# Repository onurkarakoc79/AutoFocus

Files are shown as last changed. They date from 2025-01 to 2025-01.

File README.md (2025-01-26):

## Automatic Camera Focusing System
# Overview
This project involves the development of an automatic camera focusing system utilizing a combination of Raspberry Pi, OpenCV, Python, and a servo motor. The system automates the traditionally manual process of focus adjustment, providing real-time feedback and enabling precise focus for photography, surveillance, and computer vision applications.

# Objectives
1. Automated Focus Adjustment: Control the camera lens with a servo motor for precise, remote adjustments.
2. Image Processing with OpenCV: Use a delentropy-based algorithm to assess the clarity of images.
3. Real-Time Feedback: Provide immediate focus status and save images once focused.
4. Integration: Seamlessly combine components like Raspberry Pi, servo motor, and camera module.
5. Optimization: Evaluate and refine the system for improved accuracy and efficiency.
# Features
* Focus adjustment through a servo-controlled camera lens.
* Image sharpness analysis using delentropy metrics.
* Efficient and reliable operation in varying light conditions.
* Compact design with 3D-printed custom parts.
## Components
# Hardware
* Raspberry Pi v2: Central processing unit for system integration.
* MG995 Servo Motor: Adjusts the lens focus ring.
* Raspberry Pi HQ Camera Module: Captures high-resolution images.
* LM2596 Voltage Regulator: Provides stable power supply.
* Additional components: LED lamp, 12V power supply, trapezoidal lead screw, and 3D-printed mechanical parts.
# Software
* Raspbian OS: Operating system for Raspberry Pi.
* OpenCV Library: Image processing and analysis.
* PiGPIO Library: Optimized PWM signal generator for servo motor control.
# Installation and Setup
1. Install Raspbian OS on Raspberry Pi.
2. Install the OpenCV library:

```bash
   sudo apt-get install python3-opencv
```
3. Install the PiGPIO library like described in the website:
<pre> https://abyz.me.uk/rpi/pigpio/download.html </pre>

4. Connect hardware components as per the circuit schematic.

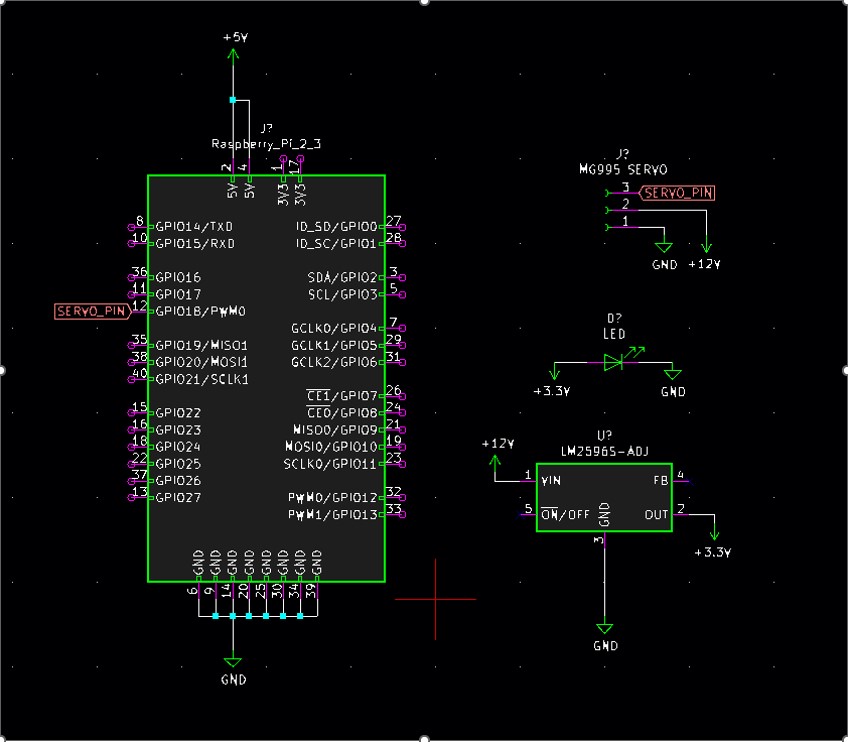
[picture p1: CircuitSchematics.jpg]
Focus Adjustment Schematic


5. Run the focus adjustment script:

```bash
   git clone https://github.com/onurkarakoc79/AutoFocus
```

# Usage
1. Power on the Raspberry Pi and connected components.
2. Adjust focus by pointing the camera at the target object.
3. Run the following script
   ```bash
    python3 AutoFocus.py
   ```
4. The system will analyze the image's clarity and automatically adjust the focus.
# Applications
* Photography: Enhanced focus precision for capturing sharp images.
* Surveillance: Continuous focus adjustments for monitoring.
* Microscopy: Precise focus on specimens for detailed analysis.
* Robotics: Improved navigation through real-time focus adjustments.
# Challenges and Solutions
* Low processing power: Optimized algorithms to focus on specific image regions.
* Servo jitter: Resolved by switching to the PiGPIO library.
* Lighting issues: Incorporated LED lamp for better illumination.
# Future Improvements
* Enhancing focus adjustment speed.
* Reducing system size for compact applications.
* Extending use cases to include robotics and industrial automation.

## Contact

If you have any questions, feedback, or inquiries related to the project, feel free to reach out to me:

My personal mail: onurkarakoc79@gmail.com

I appreciate your interest in my projects and look forward to collaborating with you in the fascinating field of scientific exploration and discovery.

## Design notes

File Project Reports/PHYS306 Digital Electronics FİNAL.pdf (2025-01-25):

## PHYS306 Digital Electronics

## Final Project: Automatic focusing of a camera on an

object.

Objectives:

The primary objective of this project is to develop an advanced automatic focus system using OpenCV, Python, a Raspberry Pi, and a servo motor. The system aims to revolutionize the traditional manual focus adjustment process by automating it through the integration of various technologies.

The first objective is to design a mechanism that enables automated focus adjustment. This will be accomplished by employing a servo motor to rotate the camera lens, allowing for precise and remote adjustments. The servo motor will be controlled through the Raspberry Pi, enabling convenient and accurate focus changes without the need for manual intervention.

The second objective involves implementing an image processing algorithm using OpenCV and Python. This algorithm will be responsible for analyzing the sharpness and clarity of captured images to determine their focus status. The delentropy metric, which measures the image's entropy and provides a measure of its clarity, will be utilized for this purpose. By calculating the delentropy of each image, the algorithm will classify them as either focused or unfocused.

Real-time focus feedback constitutes the third objective. The system will provide immediate feedback on the focus status of the camera and save the image to raspberry pi when camera on the focus status.

The fourth objective is to seamlessly integrate the various components of the system using a Raspberry Pi. Acting as the central control unit, the Raspberry Pi will facilitate
communication between the servo motor, the camera module, and the image processing algorithm. This integration will enable smooth coordination among these components, ensuring efficient and accurate automatic focus adjustments.

Lastly, the project aims to evaluate and optimize the system's performance. Through comprehensive evaluations and comparisons, the effectiveness and accuracy of the automatic focus system will be assessed. Potential optimizations will be explored to enhance the speed and precision of the focus adjustment mechanism and image processing algorithm. By continually refining and improving the system, it can offer a reliable and user-friendly solution for automatic focus adjustment in a wide range of applications, including photography, surveillance systems, and computer vision projects.

INTRODUCTION:

In the field of photography, achieving accurate focus is essential to capture sharp and clear images. Manual focus adjustments can be time-consuming and often require constant monitoring. To address this challenge, we present a project aimed at developing an automatic focus system using OpenCV, Python, a Raspberry Pi, and a servo motor. This system leverages the power of image processing algorithms and automation to achieve precise focus settings in real-time.

The primary objective of this project is to design and implement a reliable and user-friendly automatic focus mechanism that eliminates the need for manual intervention. By integrating OpenCV, a popular computer vision library, with a Raspberry Pi microcontroller and a servo motor, we aim to create a system that can dynamically adjust the camera focus based on image analysis.

The project employs the delentropy metric, a measure of image entropy, as the foundation for the image processing algorithm. By continuously analyzing the sharpness and clarity of captured images using delentropy, the algorithm determines the focus status. Once optimal focus is achieved, the system automatically captures a photo as immediate feedback.

The automatic focus system offers several advantages over traditional manual methods. Firstly, the system's ability to analyze and assess focus quality in real-time eliminates the need for constant manual monitoring, allowing users to focus on capturing the perfect shot.Additionally, the automatic focus system enhances the consistency and reliability of focus settings. By utilizing an automated mechanism driven by a servo motor, the system can achieve precise and repeatable focus adjustments, reducing the likelihood of human error or inconsistencies between shots.

The applications of this project extend beyond photography. For example, in surveillance systems, the automatic focus system can continuously monitor and adjust the focus of cameras, ensuring clear and sharp imagery of critical areas. In microscopy, the system can be utilized to maintain precise focus on specimens, aiding researchers in capturing detailed images for analysis.

Furthermore, in robotics and autonomous systems, the automatic focus system can be integrated into vision-based navigation algorithms. By adjusting the focus of cameras in real-time, robots can perceive their surroundings more accurately, leading to improved object recognition, obstacle detection, and path planning.

In conclusion, this project aims to create an automatic focus system that revolutionizes the traditional manual focus adjustment process. By combining OpenCV, Python, a Raspberry Pi, and a servo motor, we strive to provide photographers and other professionals with an efficient, reliable, and user-friendly solution for achieving precise focus settings. The subsequent sections of this report will delve into the details of the system's design, equipment used, procedures employed, calculations performed, and the results obtained, followed by discussions and comments on the system's performance and potential areas of improvement.

Equipment:

- Raspberry Pi v2: A version 2 of the Raspberry Pi, a small single-board computer.
- LM2596 Voltage Regulator
- 3.3V LED: An LED (Light-Emitting Diode) that operates on a voltage of 3.3V.
- MG995 Servo Motor:
- 12V:10A Power supply
- 3D Printed custom parts: Custom-designed parts that are manufactured using a 3D printing process, allowing for unique shapes and specifications.
- Couplings
- Trapezoidal lead screw
- 8mm Chrome-plated rod
- 5V:1.5A power supply
- 8mm roller
- 8mm gt2 pulley
- 8mm linear rollers

PROCEDURE:

SOFTWARE:

1. The Raspbian operating system will be installed on the raspberry pi card in the software part.
a. Raspbian is a specialized operating system built specifically for the Raspberry Pi. It is based on the Linux Debian distribution and provides a lightweight and user-friendly environment for running applications on the Raspberry Pi hardware. Raspbian comes with pre-installed software packages and tools, making it a popular choice for various projects and applications.
2. OpenCV library will be downloaded to raspberry pi.
a. OpenCV, or Open-Source Computer Vision Library, is a popular open-source software library used for computer vision and image processing tasks. It provides a wide range of functions and algorithms to analyze and manipulate images and videos. OpenCV is widely used in various fields, such as robotics, surveillance, augmented reality, and medical imaging. Its versatility and extensive documentation make it a valuable tool for developers working with computer vision applications.
3. Functions that can detect whether the captured image is clear or not will be investigated.
a. The cv2.Laplacian function in OpenCV is used for performing the Laplacian edge detection on an image. It calculates the Laplacian gradient of the image, which highlights regions of rapid intensity changes or edges. The Laplacian operator is a second-order derivative operator that measures the rate of change of the image intensity. It is commonly used for edge detection because it responds strongly to areas of rapid intensity variation. The cv2.Laplacian function applies the Laplacian operator to each pixel in the image and computes the Laplacian gradient. The function takes the input image as its parameter and returns the output image, which represents the edges or areas of rapid intensity changes. The resulting image is typically in grayscale, where brighter pixels indicate stronger edges. The cv2.Laplacian function uses a 3x3 kernel by default, but you can specify a different kernel size if needed. The kernel determines the neighborhood around each pixel that is used for calculating the Laplacian gradient. Overall, the cv2.Laplacian function is a powerful tool for detecting edges and areas of rapid intensity changes in an image, providing valuable information for various computer vision tasks such as object recognition, image segmentation, and feature extraction.
b. The cv2.GaussianBlur function in OpenCV is used for applying a Gaussian blur or smoothing effect to an image. Gaussian blur is a widely used image filtering technique that helps reduce noise and details in an image while preserving its overall structure. The function takes the input image and two additional parameters as input: the kernel size and the standard deviation of the Gaussian distribution. The kernel size determines the size of the filter window, which defines the neighborhood of pixels used for the blurring operation. The standard deviation controls the spread of the Gaussian distribution and influences the amount of blurring applied. When the cv2.GaussianBlur function is called, it convolves each pixel in the image with a Gaussian kernel. The convolution process involves calculating the weighted average of the pixel values within the kernel window. The weights are determined by the Gaussian distribution, with the highest weight assigned to the central pixel and decreasing weights assigned to the surrounding pixels. By convolving the image with the Gaussian kernel, the function effectively replaces each pixel value with the weighted average of its neighborhood, resulting in a smoothed and blurred version of the original image. The amount of blurring depends on the kernel size and standard deviation parameters. Larger kernel sizes and higher standard deviations result in stronger blurring effects. The cv2.GaussianBlur function is commonly used as a preprocessing step in various computer vision tasks. It helps reduce noise, remove high-frequency details, and create smoother images that are more suitable for subsequent operations such as edge detection, feature extraction, or image recognition.
c. The detect_focus_delentropy function aims to assess the focus measure of a grayscale image using the delentropy method. This method focuses on analyzing the distribution of gradients, which are changes in pixel intensities across neighboring regions. To calculate the focus measure, the function first computes the horizontal and vertical gradients of the image. This is done by subtracting the pixel values of adjacent columns and rows, respectively. By combining these gradients, an overall gradient image is obtained, representing the magnitude and direction of changes in pixel intensities. Next, the function constructs a 2D histogram based on the gradient values, which captures the distribution of these values across the image. The histogram is normalized to ensure that each bin represents a proportional frequency of gradient occurrences. The histogram is then processed by applying the logarithm (base
2) to each bin value, resulting in delentropy values. These delentropy values represent the information content or complexity associated with different gradient magnitudes. By summing up these delentropy values, an overall measure of the image's entropy is obtained. Dividing the computed entropy by 2, following the Papoulis generalized sampling method, yields the final focus measure. This measure serves as a quantitative indicator of the image's sharpness and clarity, allowing for the determination of the optimal focus setting for capturing high-quality images. In summary, the detect_focus_delentropy function utilizes the delentropy method to evaluate the focus quality of a grayscale image by analyzing the distribution of gradients. This approach provides valuable insights into the image's level of detail and sharpness, facilitating the identification of the ideal focus point for image capture.

ELECTRONICS:

1. The raspberry pi v2 will be powered and operated.
a. The Raspberry Pi 2 is a small, affordable, and versatile single-board computer. It offers improved specifications and features compared to previous models. With its compact size and GPIO pins for connecting external components, it is widely used for educational, DIY, and IoT projects. It runs various operating systems and provides a platform for learning and innovation.
2. MG995 servo motor will be driven with the help of raspberry pi and the angle variable will enable the motor to go to the desired point.
a. The MG995 servo motor is a popular type of analog servo motor commonly used in robotics and automation projects. This servo motor is known for its high torque output and accuracy. It operates based on the principle of pulse width modulation (PWM). The motor consists of a DC motor, a control circuit, and a feedback potentiometer. When a PWM signal is applied to the servo motor, it interprets the signal's pulse width to determine the desired position. The PWM signal typically has a frequency of 50 Hz, with a pulse width ranging from 1 ms to 2 ms. The motor's control circuit uses this pulse width information to drive the DC motor to the corresponding position. The control circuit inside the servo motor compares the received pulse width with the current position feedback from the potentiometer. If the two values differ, the control circuit adjusts the motor's speed and direction to move towards the desired position. Once the position matches the input signal, the control circuit stops the motor, maintaining the position until a new signal is received.
3. The Raspberry Pi HQ Camera Module camera will be connected to Raspberry Pi and image will be taken.
a. The Raspberry Pi HQ Camera Module is an official camera accessory designed specifically for the Raspberry Pi single-board computer. It is a high-quality camera module that offers advanced imaging capabilities for various applications. The HQ Camera Module features a 12.3-megapixel Sony
IMX477 image sensor, which provides excellent image quality and low-light performance. It supports interchangeable lenses, allowing users to choose different focal lengths and lens types based on their specific needs. This flexibility enables a wide range of photography and video recording possibilities. The camera module connects directly to the Raspberry Pi board via a dedicated CSI (Camera Serial Interface) port, ensuring a seamless integration and easy setup. It is supported by the official Raspberry Pi camera software, which provides a user-friendly interface and a range of features for capturing and processing images. With the Raspberry Pi HQ Camera Module, users can capture high-resolution still images, record videos in various formats, and apply image processing techniques using the Raspberry Pi's computing power. It is suitable for applications such as surveillance systems, home automation, robotics, scientific imaging, and more.
4. With the LM2596, the output of the 12V power supply will be reduced to 3.3V and the LED will be operated.
a. The LM2596 voltage regulator is a versatile integrated circuit (IC) commonly used for voltage regulation. It efficiently converts higher input voltages to lower output voltages, providing stable power for electronic devices. Its adjustable output voltage and built-in protection features make it a popular choice for various applications.

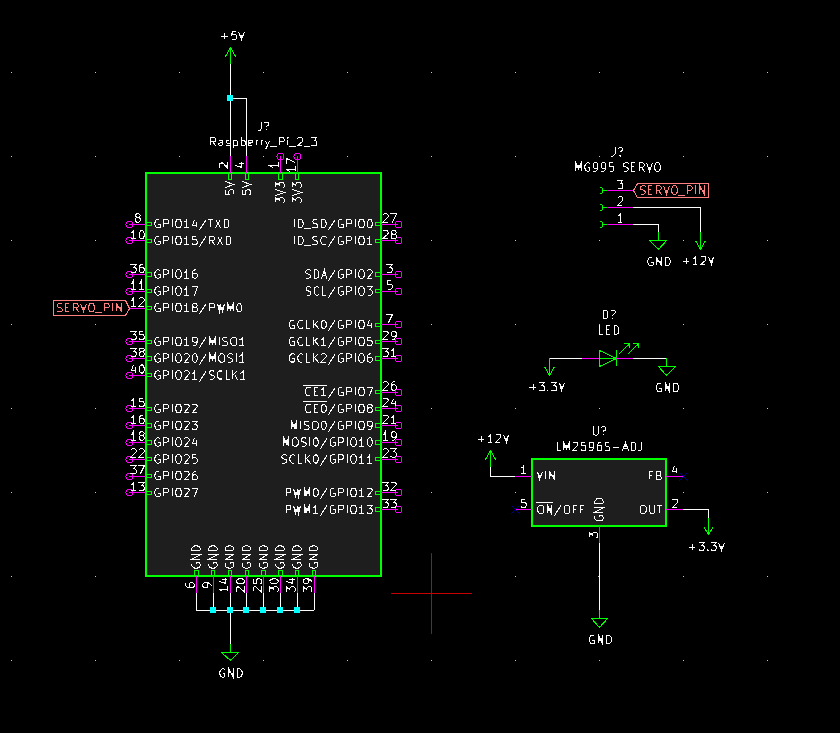
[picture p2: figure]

MECHANICHS:

1. Spur gears will be designed to control the focus ring of the lens by servo motor.
a. An adjustable focus lens with a ring refers to a type of lens that allows the user to manually adjust the focus by rotating a ring on the lens barrel. This ring controls the position of lens elements, changing the distance between them and adjusting the focal length of the lens. By rotating the ring, the user can achieve a sharp focus at different distances, allowing for versatile focusing capabilities in photography or other optical applications. This feature provides greater control and flexibility in capturing clear and detailed images or videos.
b. Module 2 spur gears refer to a type of gear mechanism that uses cylindrical gears with a standardized module of 2. The module represents the size and spacing of the

Figure 1: The circuit schematic of project gear teeth and determines their compatibility with other gears. Spur gears have straight teeth that run parallel to the gear axis and mesh together to transfer rotational motion between two parallel shafts. The module 2 designation indicates the specific size and pitch of the gear teeth, allowing for precise gear meshing and smooth power transmission. Module 2 spur gears are commonly used in various mechanical systems, such as robotics, machinery, and automotive applications, where reliable and efficient torque transfer is required.
c. The utilization of gears with 27 and 26 teeth was employed as a preventive measure against gear wear. The module 2 spur gears with these specific tooth counts were chosen to ensure a smooth and efficient transmission of motion. By using gears with different tooth counts, the system can distribute the load and minimize wear on individual gear teeth. This design choice enhances the overall durability and longevity of the gear mechanism, contributing to the reliable functioning of the system.
2. The x and y axes will be fixed with the help of two chrome shafts and linear bearings and the z axis will be moved using the trapezoidal shaft.
a. Linear rollers are mechanical components used for smooth and precise linear motion. They consist of cylindrical rollers mounted in a housing, allowing objects or loads to move along a straight path with minimal friction. They find applications in conveyor systems, sliding doors, robotics, and CNC machines, providing reliable and efficient linear movement.
b. A trapezoidal lead screw, also known as a trapezoidal thread or trapezoidal mill, is a type of mechanical component used for converting rotary motion into linear motion or vice versa. It features a trapezoidal-shaped thread profile on the surface, which allows for efficient and precise movement along its length when coupled with a corresponding nut. Trapezoidal lead screws are commonly used in applications such as CNC machines, 3D printers, and industrial machinery, offering reliable and accurate linear positioning capabilities.
3. Fixing parts designed from CAD programs will be printed with the 3D printer from PLA material.
a. PLA (Polylactic Acid) is a commonly used thermoplastic material in 3D printing. It is derived from renewable resources such as corn starch or sugarcane, making it environmentally friendly. PLA is known for its ease of use, low toxicity, and biodegradability. It has become popular in 3D printing due to its good printability, dimensional accuracy, and relatively low melting temperature.
b. 3D printing, also known as additive manufacturing, is a process of creating three-dimensional objects by depositing successive layers of material. It involves the use of a 3D printer, which reads a digital 3D model file and builds the object layer by layer. The printer melts or softens the PLA filament and extrudes it through a nozzle to create the desired shape. As each layer is added and solidified, the object gradually takes form. 3D printing offers versatility, allowing the production of complex geometries, prototypes, customized products, and even functional parts for various industries.

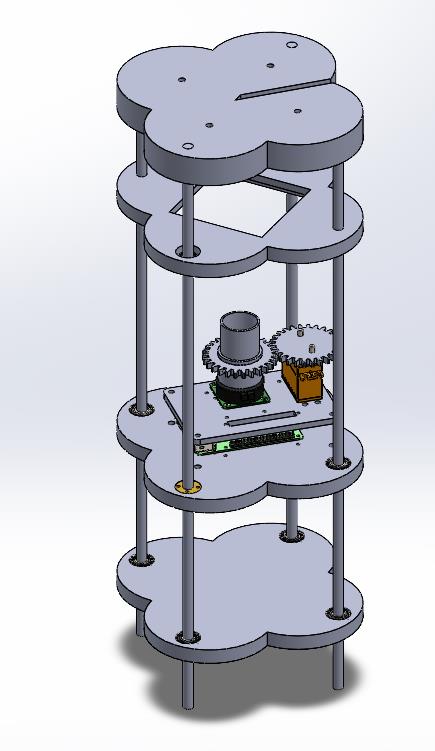
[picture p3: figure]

CALCULATİONS AND RESULTS:

SOFTWARE:

In the software development phase, the Raspberry Pi was initially set up with the Raspbian operating system, which serves as the foundation for running various applications. Subsequently, the OpenCV libraries were installed to leverage their extensive capabilities for image processing and analysis.

During the initial research phase, the Laplacian function, available in the OpenCV library, was explored as a potential method for assessing image clarity. The Laplacian function showed promising results in determining image sharpness. However, it became evident that relying solely on the Laplacian function was not sufficient, particularly in low-light conditions where its effectiveness diminished. To overcome this limitation, an adaptation of the Laplacian function using Gaussian blur was implemented. This modification aimed to improve performance in different lighting conditions.

However, the system's performance on the Raspberry Pi, which has relatively lower processing power compared to personal computers, proved to be insufficient. The computational demands of the modified Laplacian function pushed the Raspberry Pi to its limits, causing freezing and instability. As a result, alternative approaches were explored to accurately measure image sharpness.

Figure 2: The CAD drawing of mechanical parts of project

Through further investigation, the delentropy method was discovered as a viable alternative. The delentropy method proved to be reliable, particularly in low-light or high-light conditions. It was deemed more suitable for the project as it did not excessively strain the system. Consequently, the decision was made to adopt the delentropy method as the primary approach for assessing image sharpness.

To enhance program efficiency, a refinement was made by calculating the entropy of the specific point where focus was desired, rather than calculating the entropy of each pixel in the entire image. This optimization not only improved the program's efficiency but also provided users with the flexibility to focus on their desired point of interest. To facilitate point selection, the OpenCV function "setmousecallback" was utilized, enabling users to choose the desired focus point using a mouse input.

This iterative process of exploring different methods, adapting algorithms to varying lighting conditions, and ultimately adopting the delentropy method with optimized focus point selection has yielded a more robust and efficient automatic focus system. The subsequent sections of this report will delve into the specific procedures, calculations, and results obtained, followed by discussions on the system's performance and potential avenues for improvement.

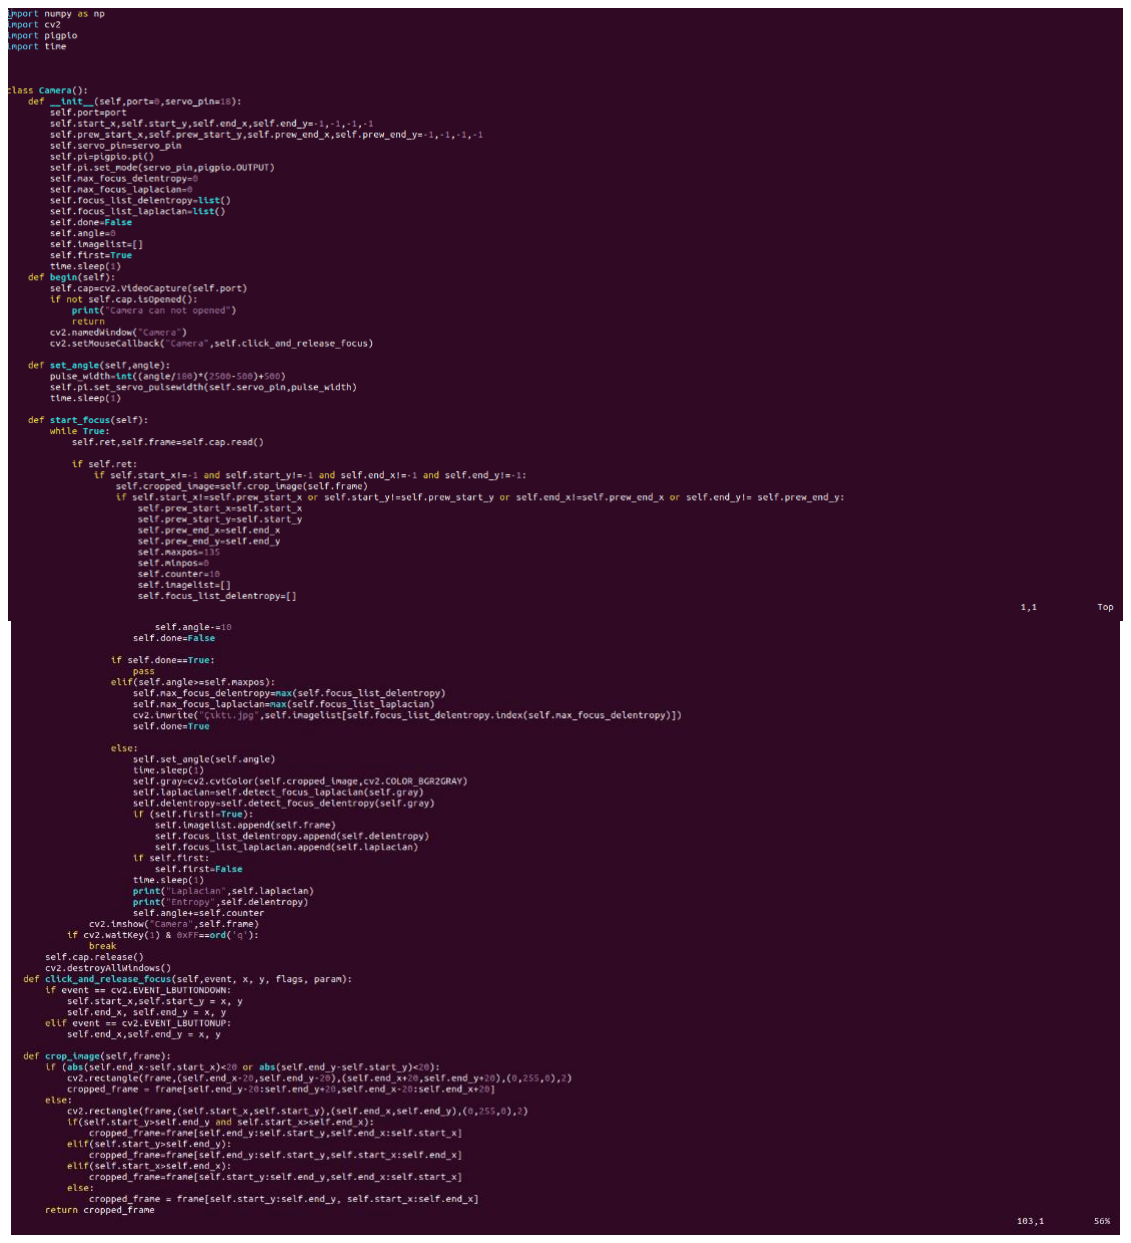
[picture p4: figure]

Figure 3: The first part of project code

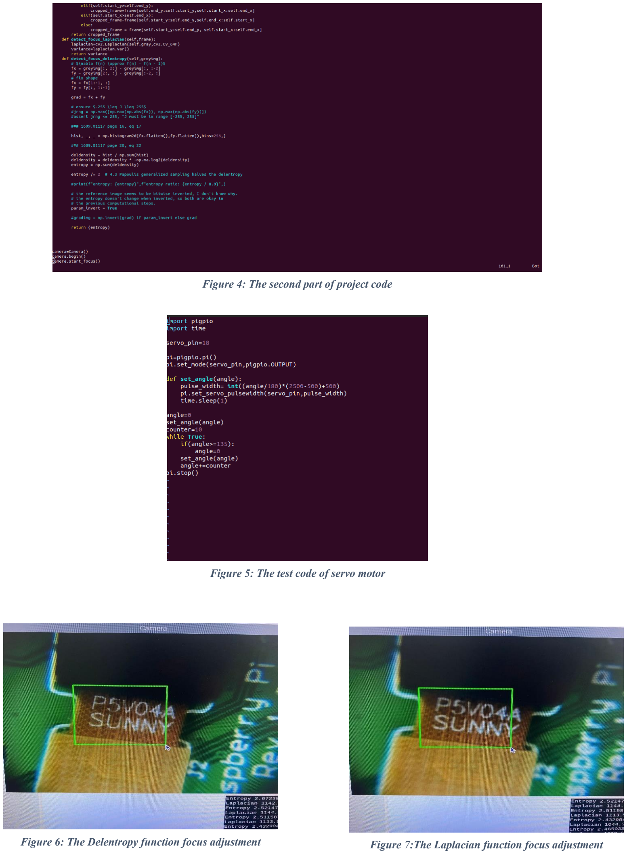
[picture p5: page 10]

Figure 4: The second part of project code

Figure 5: The test code of servo motor

Figure 6: The Delentropy function focus adjustment | Figure 7:The Laplacian function focus adjustment

ELECTRONICS:

In the electronics aspect of the project, the initial objective was to achieve focus adjustments by moving the camera in the x and y axes and zooming in and out of the object. This approach was considered due to the unavailability and high cost of lenses with adjustable focus. However, a viable alternative was found by acquiring a microscope lens, which enabled focus adjustments by manipulating the ring part of the lens instead of physically moving the camera system. To achieve this, an MG995 servo motor was deemed suitable for controlling the movement of the lens ring. Compared to the previous system, which utilized a stepper motor for x and y axis movements, this new configuration not only facilitated more precise focus adjustments but also reduced system complexity.

Since the MG995 servo motor operates on 12V, a dedicated 12V power supply was utilized, and the connections were established as depicted in the provided figure. The PWM-controlled output of the MG995 servo motor was connected to the gpio18 pin of the Raspberry Pi, while the grounds of both the Raspberry Pi and the 12V power supply were shared. Initially, the RPi library, one of the main libraries for Raspberry Pi, was employed for control. However, it was later discovered that the servo exhibited vibrations, known as servo jitter, which were attributed to the suboptimal performance of the PWM signal generator in the RPi library. As a remedy, the PiGPIO library was adopted, as its PWM signal generator functions proved to be more optimized, effectively eliminating servo jitter.

Additionally, the use of a microscope lens required bringing the lens very close to the object of observation. As a result, in some cases, insufficient light entered the lens, resulting in subpar image quality. To address this issue, a 3.3V LED lamp was incorporated beneath the system. To avoid potential damage to the Raspberry Pi, as the 3.3V lamp drew approximately 0.8A, an LM2596 voltage regulator was employed to step down the voltage from 12V to 3.3V.

The LED lamp was then powered from this regulated 3.3V source. Furthermore, a button was connected to control the on/off operation of the LED, allowing for flexibility in different lighting conditions.

Efforts were made to convert the 12V supply to 5V for the Raspberry Pi using an LM2596 voltage regulator. However, due to the unavailability of a suitable connector, manual production of the connector was attempted. Nevertheless, issues such as poor contact and potential short circuits arose at certain points, rendering the connection unreliable. Consequently, it was deemed more appropriate to power the Raspberry Pi separately with a dedicated 5V power source. As both power sources shared a common ground, no adverse effects were observed from the utilization of these two separate power feeds.

These developments in the electronics aspect of the project, including the adoption of a microscope lens with servo-controlled focus adjustments, the integration of an LM2596 voltage regulator for precise power management, and the implementation of the PiGPIO library to address servo jitter, have significantly enhanced the overall functionality and performance of the automatic focus system.

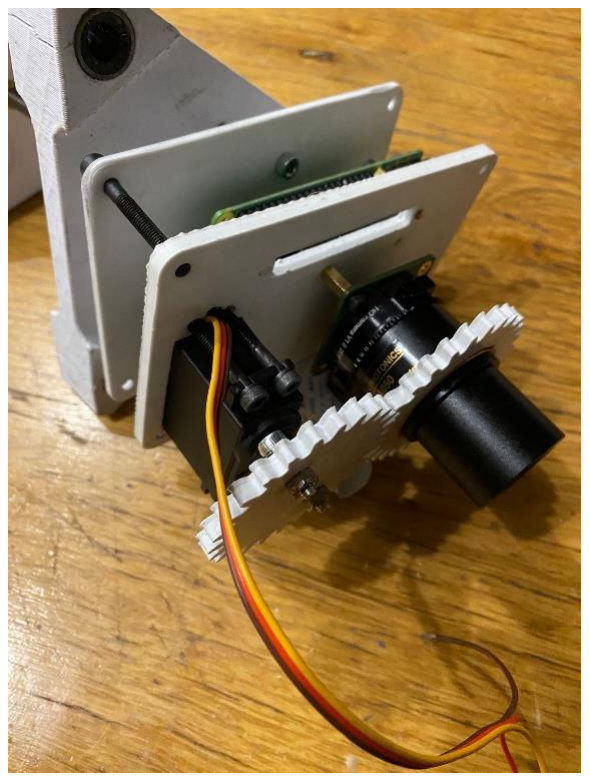
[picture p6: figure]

Figure 8: Raspberry Pi, Camera module, MG995 Servo motor combination

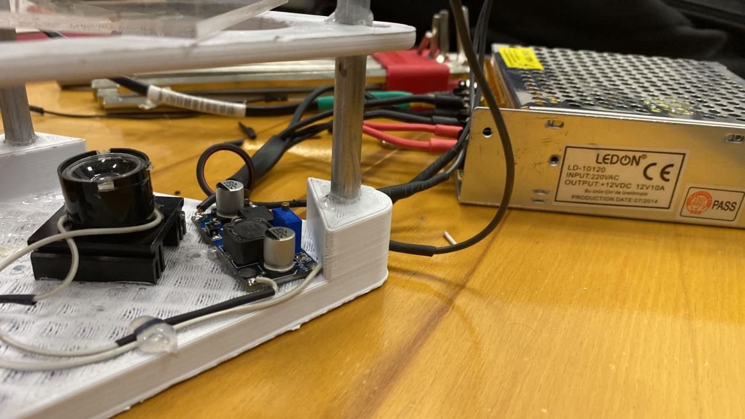
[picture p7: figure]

Figure 9: LED, LM2596 and 12V DC Power supply combination

MECHANICS:

In the mechanical aspect of the project, a series of design iterations were conducted to achieve optimal focus adjustment with the given constraints. The initial design focused on camera movement in the x and y axes to determine the ideal focus distance. However, it was observed that this approach introduced complexities and increased the overall size of the system, rendering it impractical for practical use.

To address this challenge, a new design was proposed that centered around a specific component placement, as shown in the provided figure. This design emphasized the integration of the Raspberry Pi and the servo motor, forming a compact and efficient focal adjustment module. By attaching conventional camera lenses to this module, it would be possible to achieve precise focus control and capture images without relying on additional system components.

Nevertheless, due to the utilization of a microscope lens in the current system, close proximity between the lens and the observed object was crucial. To validate the system's performance, a z-axis moving system was designed, while the x and y axes were fixed (Fig.2). To enable z-axis movement, a trapezoidal shaft was employed, coupled with a bearing and a coupling mechanism to connect it to the Raspberry Pi. This design ensured that the rotational motion of the trapezoidal shaft did not interfere with the overall system operation.This configuration allowed for testing focus accuracy at various distances. However, it was discovered that the initially proposed design exceeded the manufacturing capabilities of existing 3D printers, necessitating further refinement.

As a result, a final design was developed to overcome the production limitations. This revised design incorporated two gear systems to establish a connection between the servo motor and the motion ring of the lens. With precise positioning facilitated by the servo motor, the lens could be effectively moved using these gears.

Notably, it should be mentioned that the absence of the 3rd chrome shaft in the current system configuration (Fig.12) was due to unforeseen production tolerances with the 3D printer. Including the 3rd chrome shaft resulted in the system becoming jammed and non-functional.

Overall, the mechanical design went through an iterative process to address the specific requirements of achieving precise focus control with a microscope lens. By optimizing the design and considering the limitations of 3D printing, the final configuration successfully enabled accurate movement and positioning of the lens to attain the desired focus. The refined design showcased the importance of adaptability and innovative problem-solving in developing practical and efficient mechanical systems.

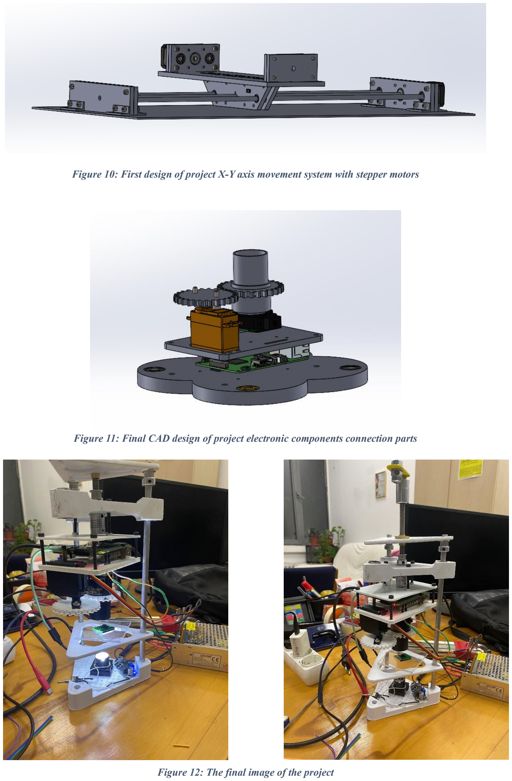
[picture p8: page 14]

Figure 10: First design of project X-Y axis movement system with stepper motors

Figure 11: Final CAD design of project electronic components connection parts

Figure 12: The final image of the project

Discussions and Comments:

The automatic camera focusing system developed in this project offers several advantages over traditional manual focusing methods. It eliminates the need for constant monitoring and adjustment of the focus ring, thereby saving valuable time and effort for photographers. By employing sophisticated image processing algorithms, the system provides real-time feedback on the sharpness and clarity of images, enabling photographers to achieve precise focus without relying on manual adjustments.

The integration of various components, including the Raspberry Pi, servo motor, camera module, and image processing algorithm, results in a seamless and automated solution. The Raspberry Pi serves as the central control unit, facilitating communication among different components and enabling precise focus adjustments through the servo motor. The image processing algorithm, implemented using OpenCV and Python, effectively analyzes image clarity, allowing the system to quickly determine the focus status of an image.

The focal point of the system lies in the meticulously designed mechanism responsible for controlling the focus ring using a servo motor. With the aid of 3D printed custom parts, couplings, a trapezoidal lead screw, and other essential components, the system achieves precise and remote focus adjustments. This mechanism, in conjunction with the image processing algorithm, forms a closed-loop system that continuously monitors and adjusts the focus to maintain optimal sharpness.

To assess the performance of the system, it is recommended to conduct thorough evaluations regarding its accuracy and speed in focus adjustments. A comparative analysis between the automatic focus system and manual focusing techniques can be performed to gauge the system's effectiveness. Additionally, gathering user feedback and conducting usability testing can provide valuable insights for further refinement and enhancement.

The automatic camera focusing system presented in this project demonstrates the potential of combining image processing, automation, and mechanical control to provide an efficient and user-friendly solution for achieving optimal focus in real-time. Its numerous advantages, including time-saving capabilities, enhanced accuracy, and overall convenience, position it as a superior alternative to manual focusing methods. Future research and development endeavors could be directed towards optimizing the system's performance and exploring potential applications beyond the realm of photography.

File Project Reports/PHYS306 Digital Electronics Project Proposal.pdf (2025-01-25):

## ONUR KARAKOÇ

2423200

### TITLE: Development of an Automatic Focusing System for Cameras using Digital Electronics and Stepper Motors

### INTRODUCTION:

The proposed project aims to develop an automatic focusing system for a camera using digital electronics. The system will use advanced algorithms to find the optical axis and adjust the position of the object to achieve optimal focus. This project has the potential to revolutionize camera imaging and have applications in various fields, from photography to medical imaging.

### PROBLEM STATEMENT:

The manual focusing of cameras can often be a time-consuming and imprecise process, especially in situations where the camera needs to focus on moving objects or in low light conditions. This project aims to develop an automatic focusing system using digital electronics to overcome these challenges and achieve precise and efficient focusing for various applications.

### PROPOSED SOLUTION:

This project proposes an automatic focusing system for cameras using digital electronics to provide a precise and efficient solution. The system will use a Raspberry Pi, two stepper motors, lasers, and photoresistors to determine the optical axis of the camera and adjust the position of the object to achieve optimal focus. Additionally, the system will incorporate image processing techniques to automatically capture the image once optimal focus has been achieved.

### COMPONENTS:

1. Raspberry Pi: serves as the main controller and runs the image processing algorithms.
2. Stepper motors (2 x NEMA17): used to adjust the position of the object.
3. Motor controllers (2 x A4988): used to control the stepper motors.
4. Laser: used to determine the optical axis of the camera.
5. Photoresistor: detects the laser and indicates when it is on the optical axis.
6. Camera: captures the images and sends them to the Raspberry Pi for processing.
7. Power supply (12V): provides power to all the components.

METHODOLOGY:

1. Hardware setup: Assemble the required hardware components, including a Raspberry Pi, two stepper motors, lasers, photoresistors, and a camera.
2. Optical axis determination: Determine the camera's optical axis using lasers and photoresistors.
3. Object positioning: Adjust the object's position in the x and y directions using the stepper motors until the image captured by the camera is in focus.
4. Image processing: Capture the image using the camera and process it to verify that it is in focus using techniques such as edge detection, contrast enhancement, and sharpness analysis.

5. Feedback system: Incorporate a feedback system that continuously monitors the image captured by the camera and adjusts the position of the object as required to maintain optimal focus.
6. Testing and validation: Test the system using a range of objects and under different lighting conditions to validate its accuracy and efficiency.
7. Optimization: Optimize the system to improve its performance using more advanced image processing techniques, optimizing the stepper motor control algorithms, and improving the feedback system.
8. Final testing and evaluation: Test the system once it is optimized to ensure that it meets the design requirements and is performing at an acceptable level.

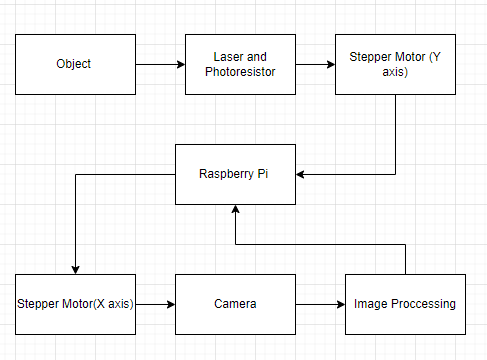
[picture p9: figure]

Figure 1: Block Diagram of the system

EXPECTED RESULTS:

Upon completion of this project, we expect to have developed an automatic focusing system for cameras using digital electronics that provides a precise and efficient solution for focusing. The system will be able to accurately determine the optical axis of the camera using lasers and photoresistors, and adjust the position of the object using two stepper motors. Additionally, the system will incorporate image processing techniques to automatically capture the image once optimal focus has been achieved. We anticipate that this system will significantly reduce the time required for manual focusing and increase the precision and accuracy of focusing. The system has the potential to be applied in various fields, including photography, medical imaging, and robotics.

### TROUBLESHOOTING:

In case of any issues, the system will be tested and optimized to ensure maximum efficiency and accuracy. Troubleshooting steps will include testing the hardware components, adjusting the software algorithms, and optimizing the system settings.

### CONCLUSION:

The proposed project aims to develop an automatic focusing system for cameras using digital electronics and stepper motors. The system will provide a precise and efficient solution to the challenges faced in manual focusing of cameras. The project has the potential to revolutionize camera imaging and have applications in various fields.

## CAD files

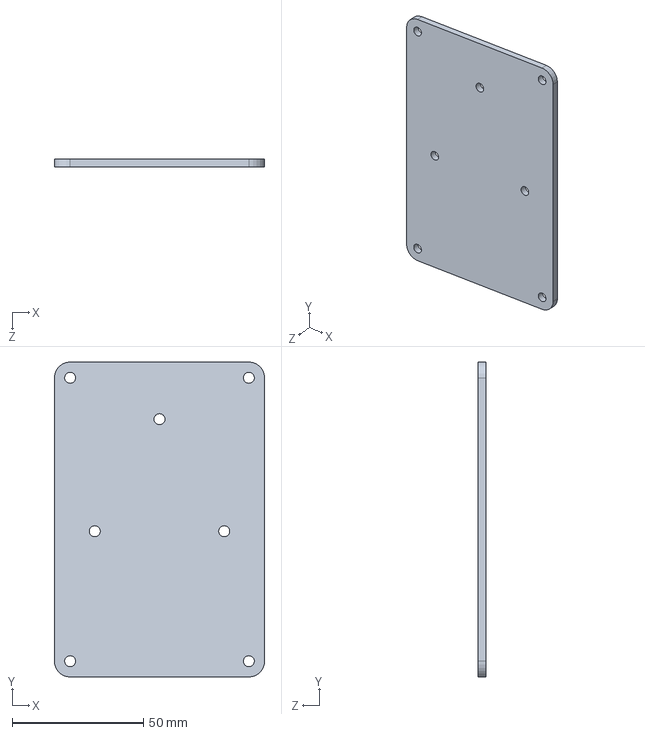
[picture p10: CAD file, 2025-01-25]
3D Drawings/v3/ara parça sabitleme.SLDPRT
80.0 x 119.9 x 3.00 mm

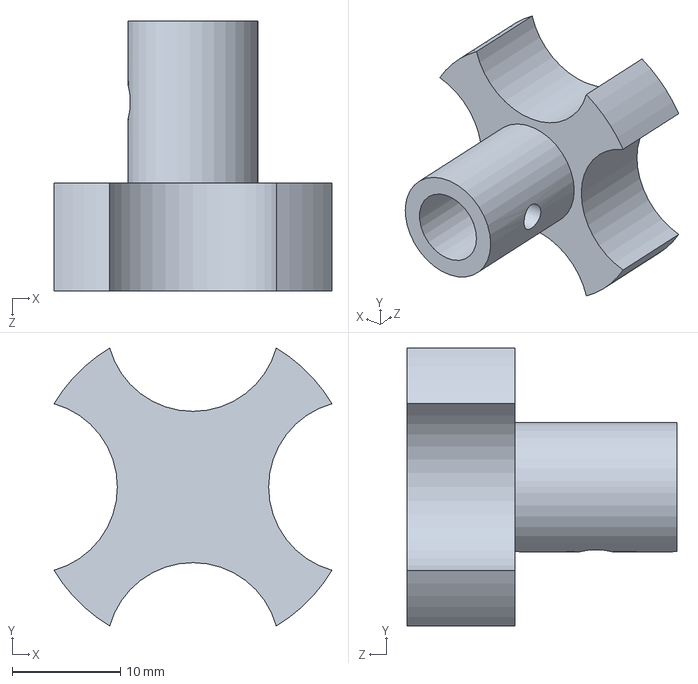
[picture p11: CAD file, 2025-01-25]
3D Drawings/v3/trapez mili hareket parçası.SLDPRT
25.7 x 25.7 x 25.0 mm

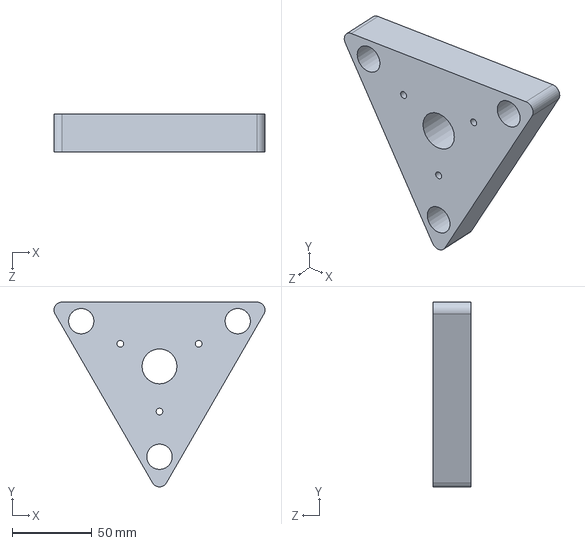
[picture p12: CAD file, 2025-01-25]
3D Drawings/v3/ara parça.SLDPRT
132.7 x 116.2 x 24.0 mm

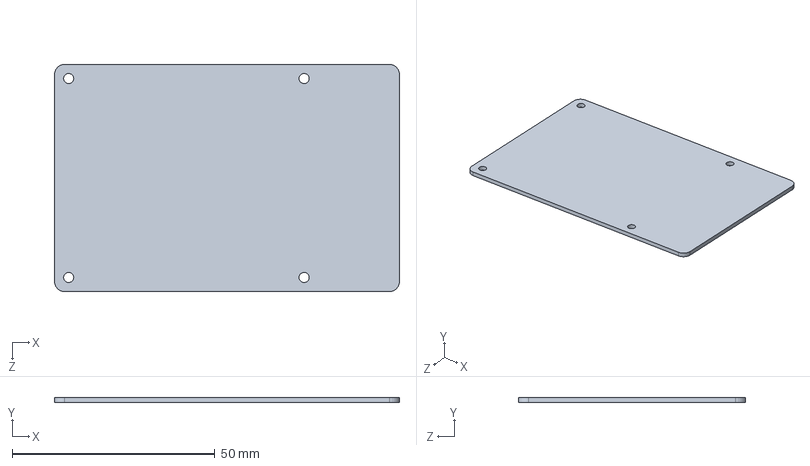
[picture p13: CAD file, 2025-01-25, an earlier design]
3D Drawings/v2/raspberry v2/Mainboard2.SLDPRT
85.0 x 1.30 x 56.0 mm

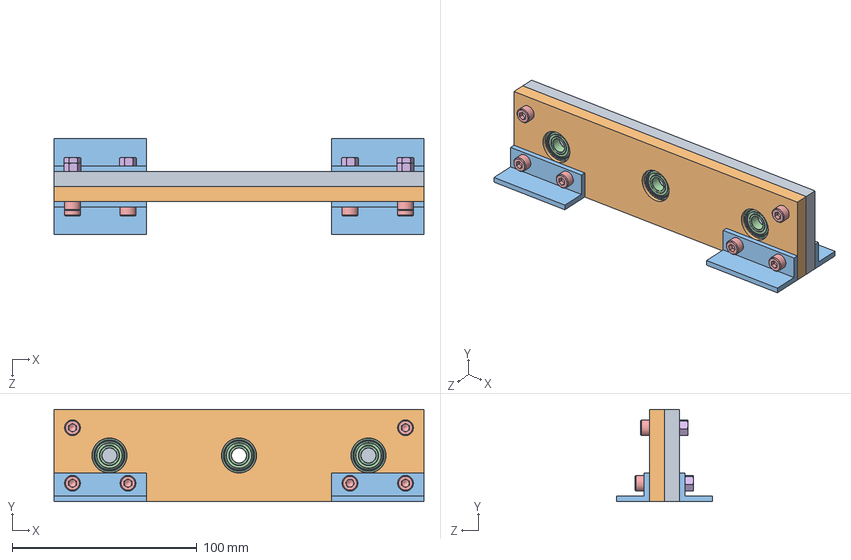
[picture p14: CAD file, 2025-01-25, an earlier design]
3D Drawings/v1/y eksen rulman tarafı bağlantı.SLDASM
200.0 x 50.0 x 52.0 mm
y eksen bağlantısı ikinci parça
y eksen bağlantısı ilk parça
3d ara parça x 4
698zz Bearing x 3
socket head cap screw_am x 6
hex nut style 1_am x 6

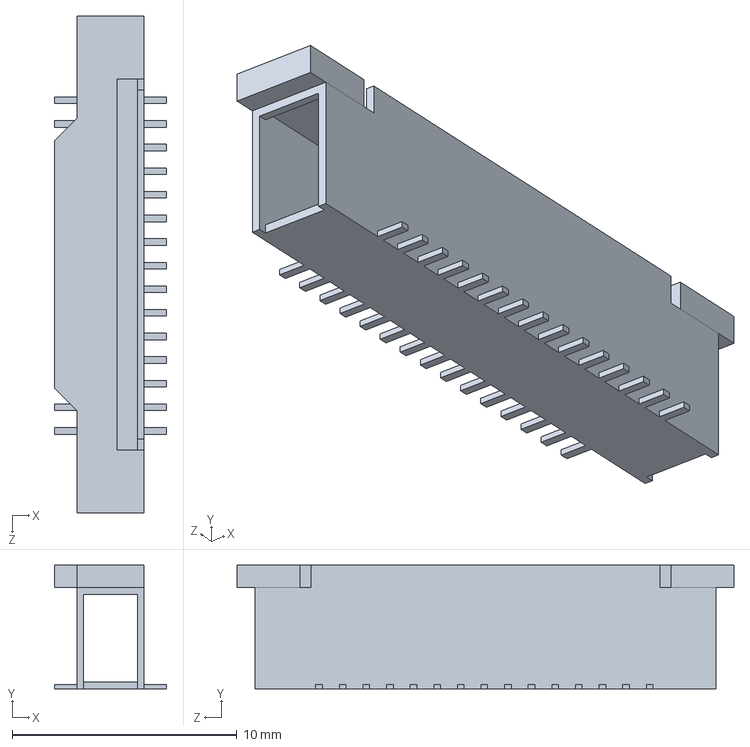
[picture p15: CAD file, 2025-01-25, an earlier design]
3D Drawings/v2/raspberry v2/CameraAssembly.SLDPRT
5.00 x 5.50 x 22.1 mm

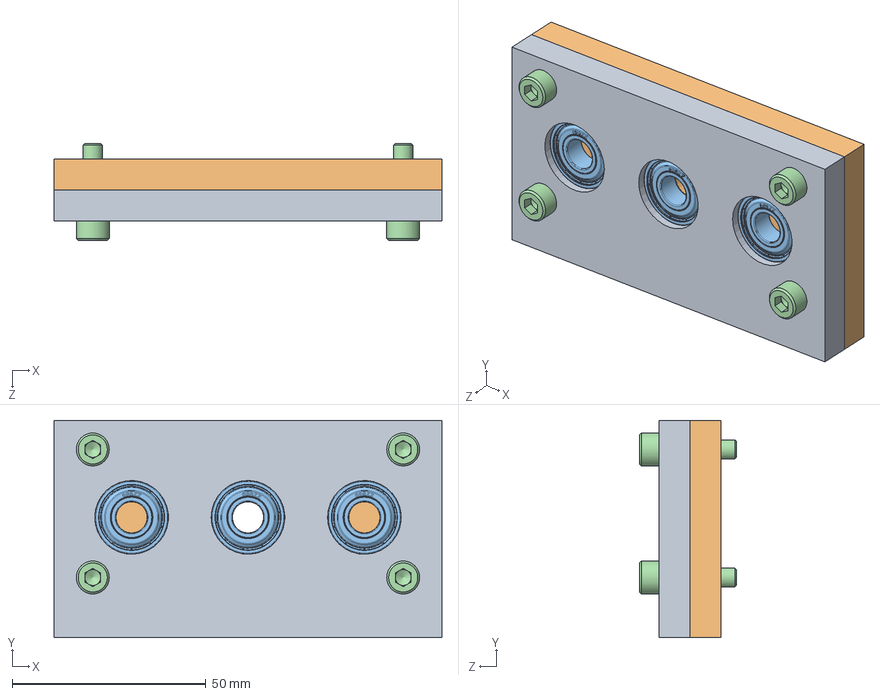
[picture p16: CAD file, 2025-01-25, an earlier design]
3D Drawings/v1/x ekseni rulman bağlantı parçası montaj.SLDASM
100.0 x 56.0 x 25.0 mm
x ekseni rulman bağlantısı parçası
x ekseni rulman bağlantısı parçası 2
698zz Bearing x 3
socket head cap screw_am x 4

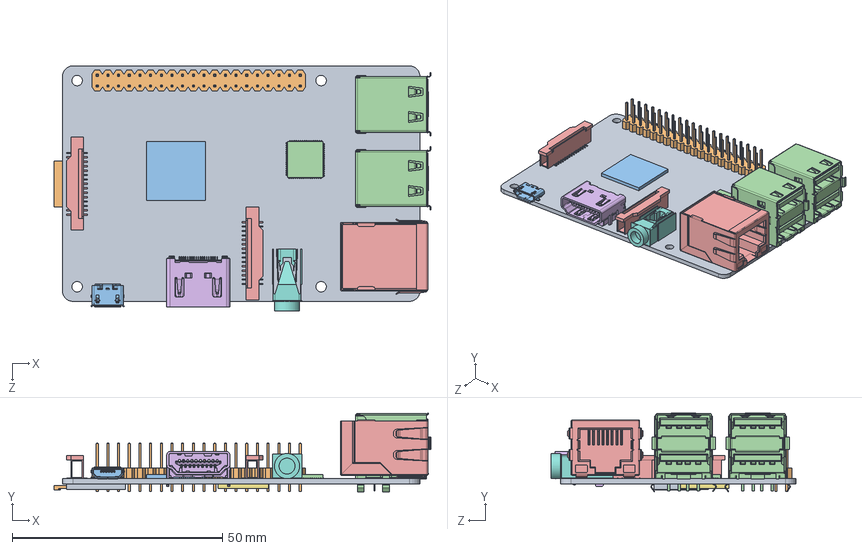
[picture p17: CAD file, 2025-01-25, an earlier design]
3D Drawings/v2/RaspberryPi2 model B SW.SLDASM
89.6 x 18.7 x 58.3 mm
Mainboard2
GPIO
Processor
GPU
CameraAssembly x 2
hdmi
RAM
Audio
MicroSDSocket
MicroSD
micro USB2
usb double x 2
RJ45-LED

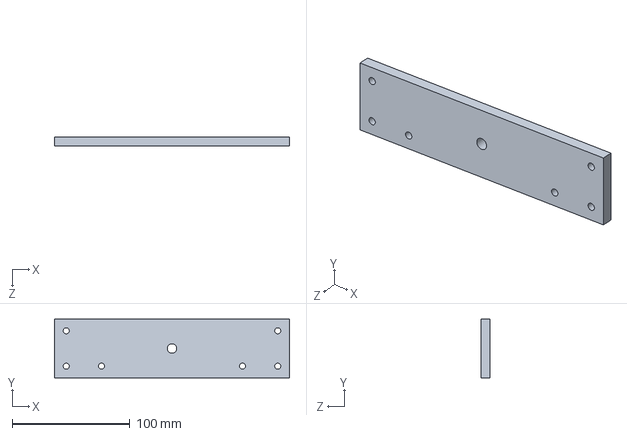
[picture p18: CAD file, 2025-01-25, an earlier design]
3D Drawings/v1/y eksen bağlantısı ikinci parça.SLDPRT
200.0 x 50.0 x 8.00 mm

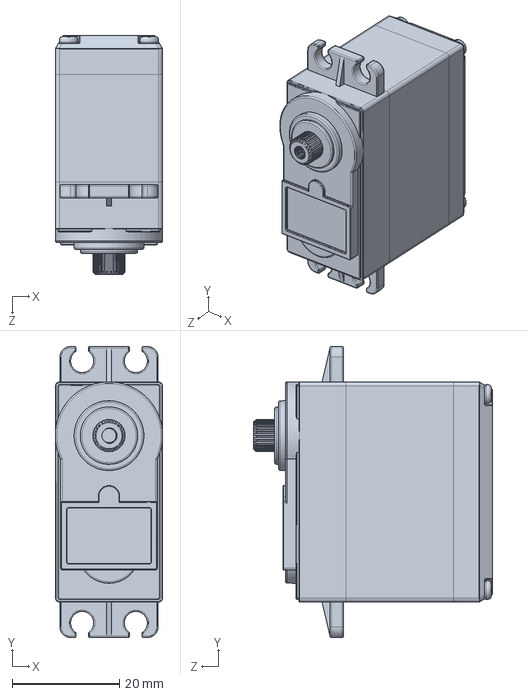
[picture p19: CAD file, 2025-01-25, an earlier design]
3D Drawings/v2/MG995-MG996R Servo.SLDPRT
20.0 x 54.2 x 44.6 mm

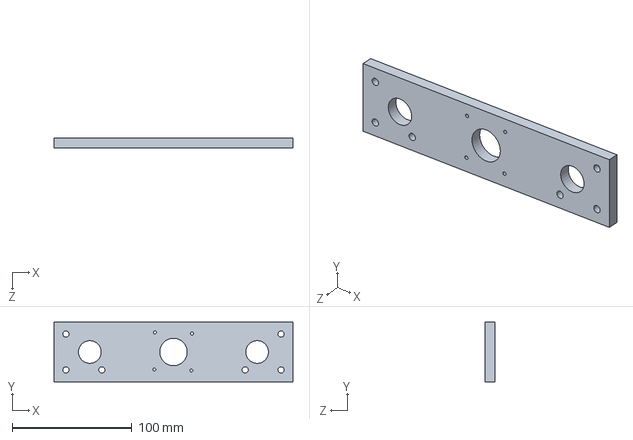
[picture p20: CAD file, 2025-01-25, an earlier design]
3D Drawings/v1/motor bağlantısı ilk parça.SLDPRT
200.0 x 50.0 x 8.00 mm

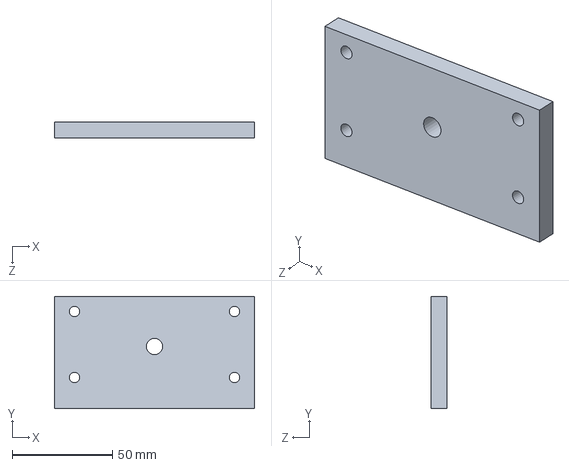
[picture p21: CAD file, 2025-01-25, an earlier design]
3D Drawings/v1/x ekseni rulman bağlantısı parçası 2.SLDPRT
100.0 x 56.0 x 8.00 mm

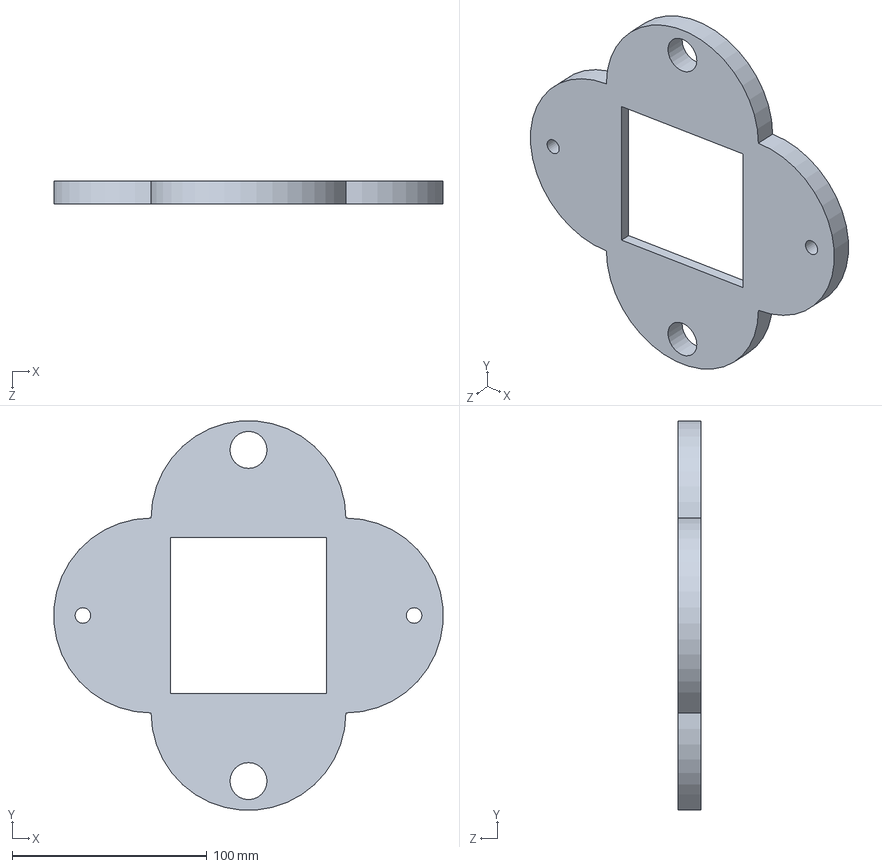
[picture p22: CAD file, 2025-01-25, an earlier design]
3D Drawings/v2/cisim lambası.SLDPRT
199.7 x 199.7 x 12.0 mm

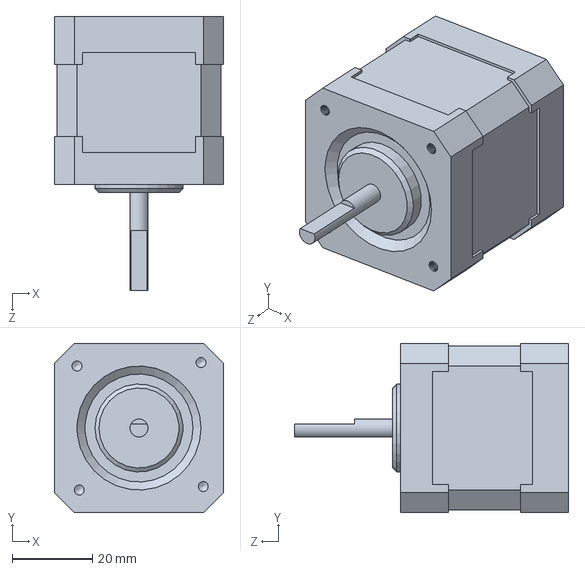
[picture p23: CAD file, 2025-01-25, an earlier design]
3D Drawings/v1/NEMA 17 STEPPER.SLDPRT
42.3 x 42.3 x 68.5 mm

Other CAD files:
3D Drawings/v2/raspberry v2/RAM.sldprt
3D Drawings/v2/raspberry v2/Processor.sldprt
3D Drawings/v2/raspberry v2/GPU.sldprt
3D Drawings/v2/raspberry v2/RJ45-LED.SLDPRT
3D Drawings/v1/1.Linear Bearing-LM8UU.SLDPRT
3D Drawings/v1/3d ara parça.SLDPRT
3D Drawings/v1/8mm çap 650mm krom mil.SLDPRT
3D Drawings/v1/Brass Screw.SLDPRT
3D Drawings/v1/Limit_Switch.SLDPRT
3D Drawings/v1/motor bağlantısı ikinci parça.SLDPRT
3D Drawings/v1/x ekseni motor bağlantısı parçası 2.SLDPRT
3D Drawings/v1/x ekseni motor bağlantısı parçası.SLDPRT
3D Drawings/v1/x ekseni rulman bağlantısı parçası.SLDPRT
3D Drawings/v1/x ekseni zemin parça.SLDPRT
3D Drawings/v1/x ekseni üst.SLDPRT
3D Drawings/v1/y eksen bağlantısı ilk parça.SLDPRT
3D Drawings/v1/zemin.SLDPRT
3D Drawings/v2/50 cm mil.SLDPRT
3D Drawings/v2/Brass Screw.SLDPRT
3D Drawings/v2/MG995_Gear2.SLDPRT
3D Drawings/v2/Raspberry Pi HQ Camera.SLDPRT
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

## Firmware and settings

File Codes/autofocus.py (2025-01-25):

import numpy as np
import cv2
import pigpio
import time 



class Camera():
    def __init__(self,port=0,servo_pin=18):
        self.port=port
        self.start_x,self.start_y,self.end_x,self.end_y=-1,-1,-1,-1
        self.prew_start_x,self.prew_start_y,self.prew_end_x,self.prew_end_y=-1,-1,-1,-1
        self.servo_pin=servo_pin
        self.pi=pigpio.pi()
        self.pi.set_mode(servo_pin,pigpio.OUTPUT)
        self.max_focus_delentropy=0
        self.max_focus_laplacian=0
        self.focus_list_delentropy=list()
        self.focus_list_laplacian=list()
        self.done=False
        self.angle=0
        self.imagelist=[]
        self.first=True
        time.sleep(1)
    def begin(self):
        self.cap=cv2.VideoCapture(self.port)
        if not self.cap.isOpened():
            print("Camera can not opened")
            return
        cv2.namedWindow("Camera")
        cv2.setMouseCallback("Camera",self.click_and_release_focus)

    def set_angle(self,angle):
        pulse_width=int((angle/180)*(2500-500)+500)
        self.pi.set_servo_pulsewidth(self.servo_pin,pulse_width)
        time.sleep(1)

    def start_focus(self):
        while True:
            self.ret,self.frame=self.cap.read()
           
            if self.ret:
                if self.start_x!=-1 and self.start_y!=-1 and self.end_x!=-1 and self.end_y!=-1:
                    self.cropped_image=self.crop_image(self.frame)
                    if self.start_x!=self.prew_start_x or self.start_y!=self.prew_start_y or self.end_x!=self.prew_end_x or self.end_y!= self.prew_end_y: 
                        self.prew_start_x=self.start_x
                        self.prew_start_y=self.start_y
                        self.prew_end_x=self.end_x
                        self.prew_end_y=self.end_y
                        self.maxpos=135
                        self.minpos=0
                        self.counter=10
                        self.imagelist=[]
                        self.focus_list_delentropy=[]
                        self.focus_list_laplacian=[]
                        self.first=True
                        while True:
                            if(self.angle<=0):
                                self.angle=0
                                break
                            self.angle-=10
                        self.done=False
                    
                    if self.done==True:
                        pass
                    elif(self.angle>=self.maxpos):
                        self.max_focus_delentropy=max(self.focus_list_delentropy)
                        self.max_focus_laplacian=max(self.focus_list_laplacian)
                        cv2.imwrite("Çıktı.jpg",self.imagelist[self.focus_list_delentropy.index(self.max_focus_delentropy)])
                        self.done=True
                        
                    else:
                        self.set_angle(self.angle)
                        time.sleep(1)
                        self.gray=cv2.cvtColor(self.cropped_image,cv2.COLOR_BGR2GRAY)
                        self.laplacian=self.detect_focus_laplacian(self.gray)
                        self.delentropy=self.detect_focus_delentropy(self.gray)
                        if (self.first!=True):
                            self.imagelist.append(self.frame)
                            self.focus_list_delentropy.append(self.delentropy)
                            self.focus_list_laplacian.append(self.laplacian)
                        if self.first:
                            self.first=False
                        time.sleep(1)
                        print("Laplacian",self.laplacian)
                        print("Entropy",self.delentropy)
                        self.angle+=self.counter 
                cv2.imshow("Camera",self.frame)
            if cv2.waitKey(1) & 0xFF==ord('q'):
                break
        self.cap.release()
        cv2.destroyAllWindows()
    def click_and_release_focus(self,event, x, y, flags, param):
        if event == cv2.EVENT_LBUTTONDOWN:
            self.start_x,self.start_y = x, y
            self.end_x, self.end_y = x, y
        elif event == cv2.EVENT_LBUTTONUP:
    	    self.end_x,self.end_y = x, y
    
    def crop_image(self,frame):
        if (abs(self.end_x-self.start_x)<20 or abs(self.end_y-self.start_y)<20):
            cv2.rectangle(frame,(self.end_x-20,self.end_y-20),(self.end_x+20,self.end_y+20),(0,255,0),2)
            cropped_frame = frame[self.end_y-20:self.end_y+20,self.end_x-20:self.end_x+20]
        else:
            cv2.rectangle(frame,(self.start_x,self.start_y),(self.end_x,self.end_y),(0,255,0),2)
            if(self.start_y>self.end_y and self.start_x>self.end_x):
                cropped_frame=frame[self.end_y:self.start_y,self.end_x:self.start_x]
            elif(self.start_y>self.end_y):
                cropped_frame=frame[self.end_y:self.start_y,self.start_x:self.end_x]
            elif(self.start_x>self.end_x):
                cropped_frame=frame[self.start_y:self.end_y,self.end_x:self.start_x]
            else:
                cropped_frame = frame[self.start_y:self.end_y, self.start_x:self.end_x]
        return cropped_frame
    def detect_focus_laplacian(self,frame):
        laplacian=cv2.Laplacian(self.gray,cv2.CV_64F)
        variance=laplacian.var()
        return variance
    def detect_focus_delentropy(self,greyimg):
        # $\nabla f(n) \approx f(n) - f(n - 1)$
        fx = greyimg[:, 2:] - greyimg[:, :-2]
        fy = greyimg[2:, :] - greyimg[:-2, :]
        # fix shape
        fx = fx[1:-1, :]
        fy = fy[:, 1:-1]

        grad = fx + fy

        # ensure $-255 \leq J \leq 255$
        #jrng = np.max([np.max(np.abs(fx)), np.max(np.abs(fy))])
        #assert jrng <= 255, "J must be in range [-255, 255]"

        ### 1609.01117 page 16, eq 17

        hist, _, _ = np.histogram2d(fx.flatten(),fy.flatten(),bins=256,)

        ### 1609.01117 page 20, eq 22

        deldensity = hist / np.sum(hist)
        deldensity = deldensity * -np.ma.log2(deldensity)
        entropy = np.sum(deldensity)

        entropy /= 2  # 4.3 Papoulis generalized sampling halves the delentropy
        
        #print(f"entropy: {entropy}",f"entropy ratio: {entropy / 8.0}",)

        # the reference image seems to be bitwise inverted, I don't know why.
        # the entropy doesn't change when inverted, so both are okay in
        # the previous computational steps.
        param_invert = True

        #gradimg = np.invert(grad) if param_invert else grad

        return (entropy)




camera=Camera()
camera.begin()
camera.start_focus()
